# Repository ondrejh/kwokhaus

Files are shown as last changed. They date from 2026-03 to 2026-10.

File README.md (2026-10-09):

# Kwokhaus

Attempt on some eggish automation.

# ToDo

- [ ] remote setting
- [ ] non volatile config (not hard coded)

---

## Kwokhaus

- door motor controll
- remote connection with Meshtastic (encrypted LoRa)
- Home Assistant integration

## Kwakhaus

### Lock

Simple lock controll with serial connection to Meshtastic.

Source directory fw/src_lock

- [x] clear project (remove display and rtc)
- [x] check lock / unlock response
- [x] create unlock trigger (remote only)
- [x] repeat status message every half an hour

- [x] connect meshtastic message to home assistant
- [x] find out how to send messages from home assistant

- [ ] light with dimmer
- [ ] return more info on status (voltage, temperature, ect.)

#### Communication protocol

function | command | answer | example
--- | --- | --- | ---
get status | NAME ? | NAME: LODKED/UNLOCKED | RX: ``KWAK ?```
| | | | TX: ```KWAK: LOCKED/UNLOCKED```
unlock | NAME UNLOCK | | RX: ```KWAK UNLOCK```
| | | |
status change | | NAME LOCKED/UNLOCKED | TX: ```KWAK: LOCKED/UNLOCKED```

#### Building, flashing

From source directory ```fw``` run ```./rebuild_lock.sh```. Reset the board to bootloader by ```./utils/reset.sh```, flash it by ```./utils/flash.sh```.

#### Connecting MQTT to HA

Let there be ```mqtt.yaml``` file in your config. And let there be in you ```configuration.yaml``` file line ```mqtt: !include mqtt.yaml```. Than, somewhere it the file there shoul be:

```
  - name: "MediumFast Last Message"
    unique_id: "mediumfast_last_message"
    state_topic: !secret meshtastic_mediumfast_topic
    value_template: >-
      {% if value_json.payload.text is defined %}
        {{ (value_json.payload.text) }}
      {% else %}
        {{ this.state }}
      {% endif %}
```

Note that, you also need to have secret definition in your secret.yaml file. This is how HA works. Love it or hate it.

From now on, youre having last MediumFast message in sensor.medium_fast_message entity. One can probably imagine how to change this for his own secret channel. Cause the otherone can probably imagine, its not a good idea to have LOCK driver connected to the public channel.

### Key

Dedicated Meshtastic connected device, monitoring Lock status. It has an RGB led to indicate whether lock is locked or unlocked. It also has the button to unlock it remotelly.

#### ToDo

- [x] chatch lock unlock messages, display
- [x] detect button press, send unlock message
- [x] send status request when no status update

##### Technical

- [ ] wifi, mqtt reconnecting
- [ ] mqtt dedicated files (not to plague main)

#### Features

- button
  - to unlock remote lock
- rgb led
  - to indicate remote lock status
- mqtt connection
  - bridge between secret Meshtastic channel and MQTT
  - backup channel for HA, in case main transceiver doesn't work

#### Prototype

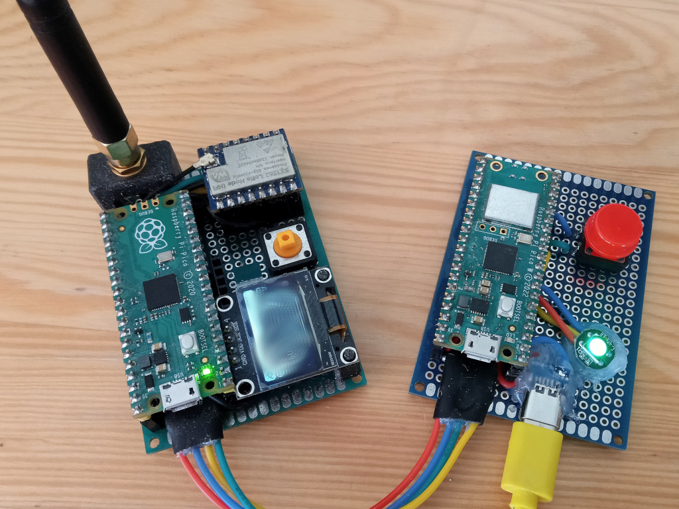
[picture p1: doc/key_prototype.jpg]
KwakKey prototype with ohM3 meshtastic modem


---

Obsolette

### Idea (not to forget)

- rubber duck splash screen

### Siple tasks

- [x] trigger by pushbutton (test)
- [ ] trigger on time
- [ ] send status on idle (every 15 minutes)
- [ ] send status on event
- [ ] draw display function chart
- [x] create and test function to store data in flash (or find lib)
  - improve nvdata.c/h
- [x] parse incoming messages
  - [x] reply on ?
  - [x] T to set time
  - [x] Z to set zone
  - [x] U to set unlock time
- [x] simple pushbutton (any bool input) filtering
- [ ] measure trigger charge voltage

### Hardware needed

- [x] rtc module
- [x] display
- [x] communication port (uart)
- [ ] charge pump
  - to charge trigger from lower voltage (single lipo)

### Functionality and features

- [x] filter incoming messages
- [x] show time
- [x] set time
- [x] set trigger time
- [ ] set time, trigger and zone localy (button, display)
- [ ] trigger on time
- [ ] showing status on display (unlocked, locked, next unlock in ..)
- [x] remote addministration by com. port

### Communication protocol (so far)

function | command | answer | example
--- | --- | --- | ---
get status | NAME ? | NAME LODKED/UNLOCKED Uhh:mm Thh:mm(z) | RX: ```KWAK ?```
| | | | TX: ```KWAK: LOCKED U11:03 T10:08(+2)```
set local time | NAME Thh:mm | NAME: Thh:mm | RX: ```KWAK T12:00```
| | | | TX: ```KWAK: T12:00```
set unlock time (local) | NAME Uhh:mm | NAME: Uhh:mm | RX: ```KWAK U12:01```
| | | | TX: ```KWAK: U12:01```
set zone | NAME Z+/-z | NAME: Z+/-z | RX: ```KWAK Z+1```
| | | | TX: ```KWAK: Z+1```

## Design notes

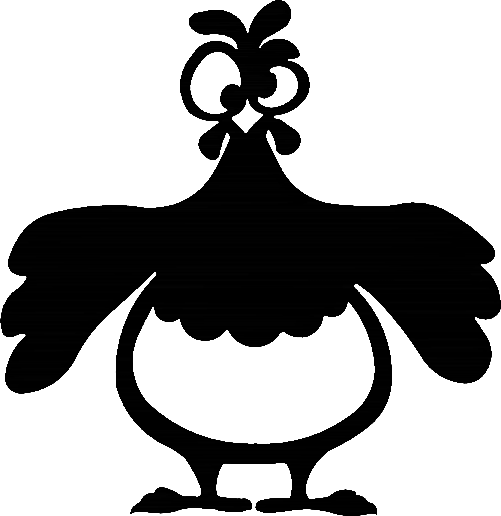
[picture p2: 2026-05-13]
jine/slepice.png

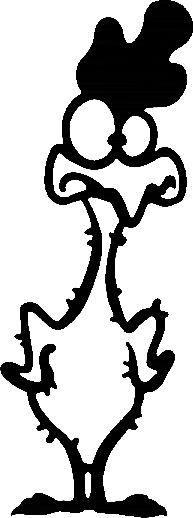
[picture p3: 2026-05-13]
jine/kohout.png

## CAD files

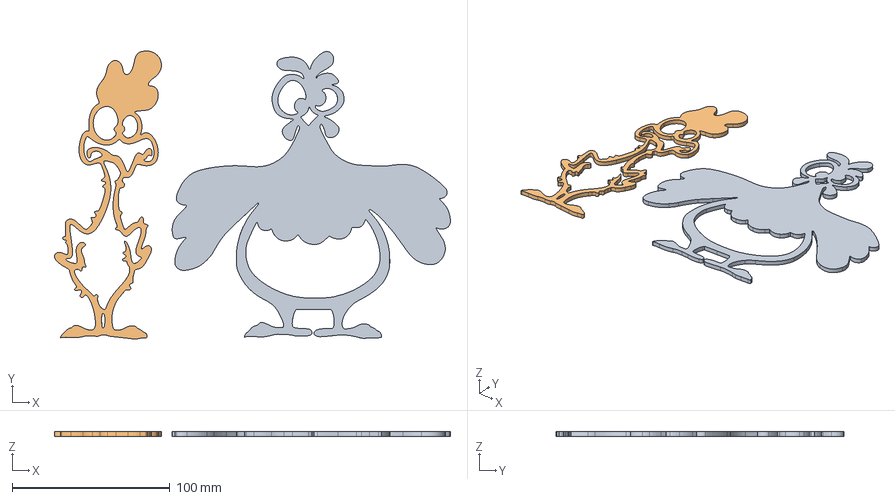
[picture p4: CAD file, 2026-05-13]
jine/obraz.FCStd
251.1 x 182.7 x 3.00 mm
slepice
kohout

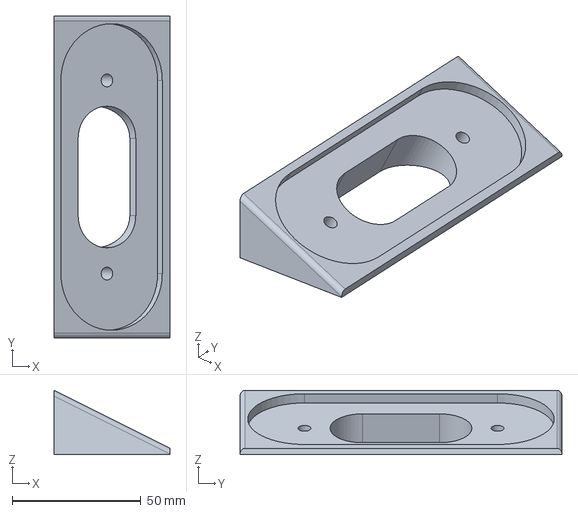
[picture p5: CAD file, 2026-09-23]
model/svetlo.FCStd
45.0 x 125.0 x 25.0 mm

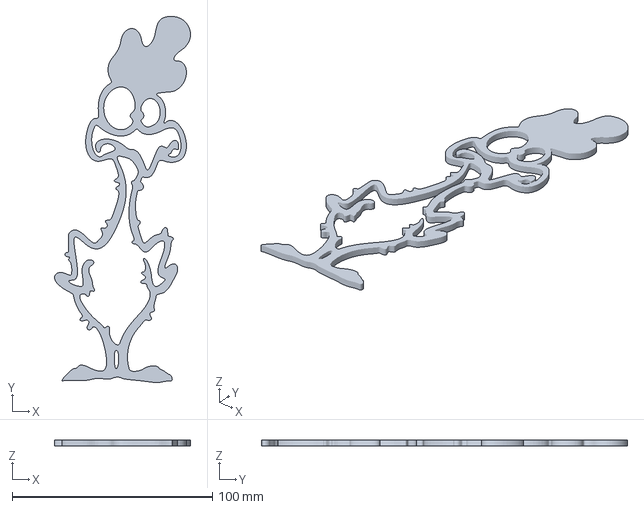
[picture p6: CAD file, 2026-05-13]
jine/kohout.3mf
67.8 x 182.7 x 3.00 mm

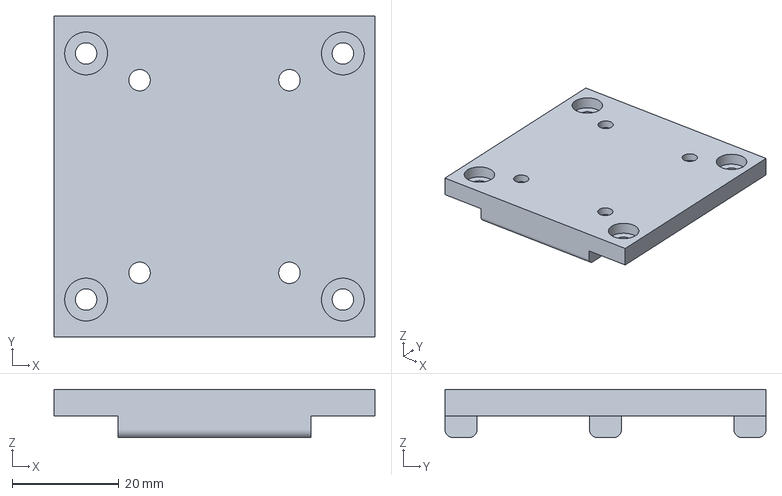
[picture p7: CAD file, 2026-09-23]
model/zdroj-plate.3mf
60.0 x 60.0 x 9.00 mm

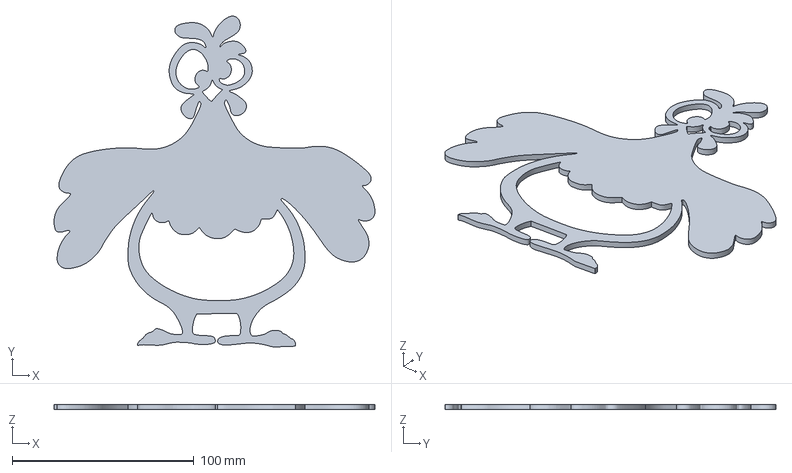
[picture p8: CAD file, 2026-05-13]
jine/slepice.3mf
176.5 x 181.9 x 3.00 mm

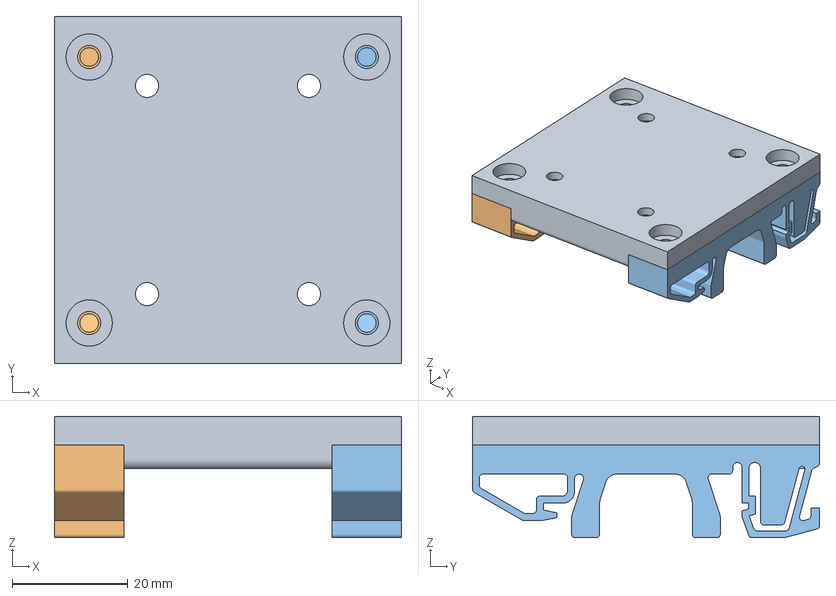
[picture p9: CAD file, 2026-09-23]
model/zdroj.FCStd
60.0 x 60.0 x 21.0 mm
plate
dins_clip1
dins_clip2

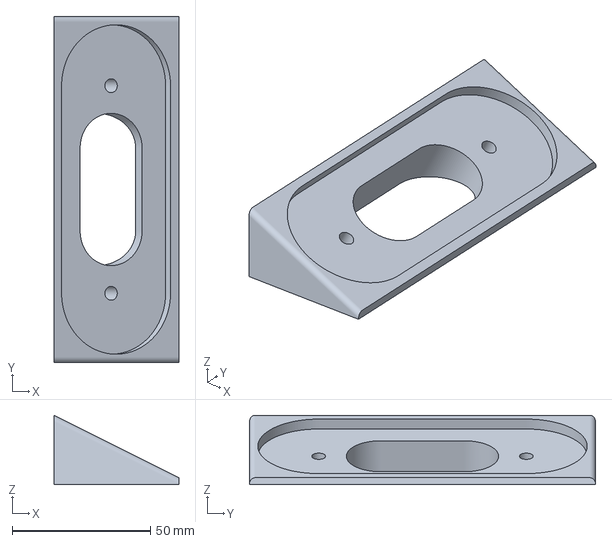
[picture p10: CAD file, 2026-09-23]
model/svetlo-holder.3mf
45.0 x 125.0 x 25.0 mm

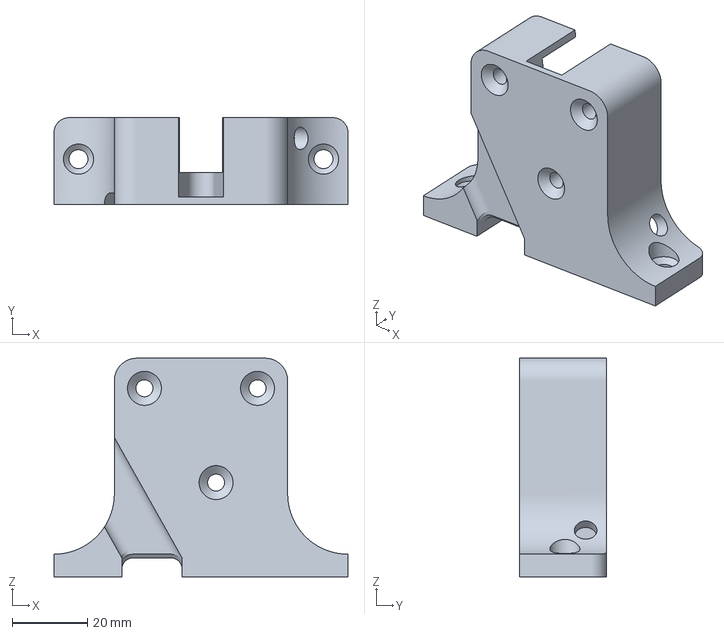
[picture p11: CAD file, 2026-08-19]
model/zamek_kachnik_vetsi-drzak_zamku.3mf
78.0 x 23.0 x 58.0 mm

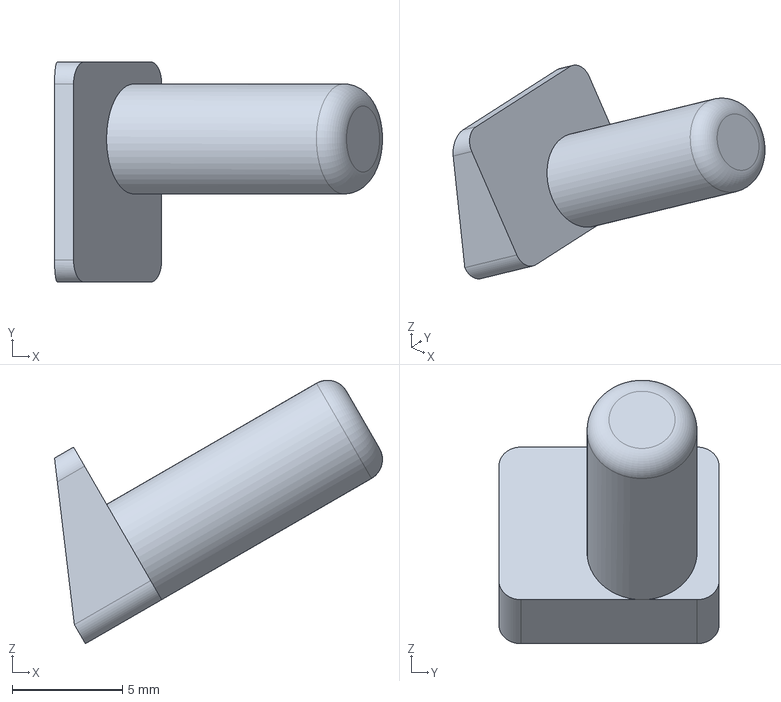
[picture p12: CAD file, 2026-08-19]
model/zamek_kachnik_vetsi.FCStd
14.9 x 10.0 x 12.0 mm

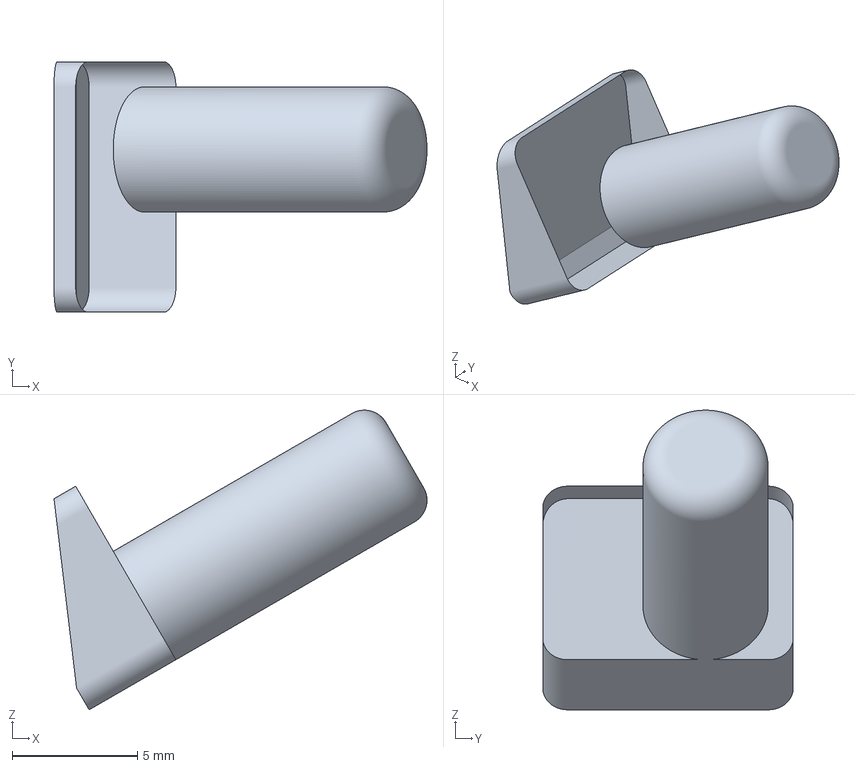
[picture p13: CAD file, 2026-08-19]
model/zamek_kachnik_vetsi-cudlik.3mf
14.9 x 10.0 x 12.0 mm

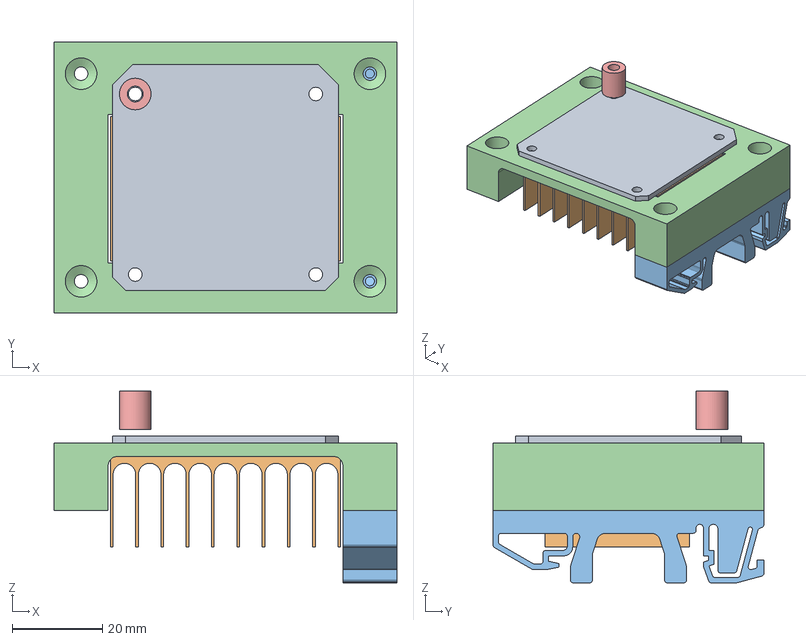
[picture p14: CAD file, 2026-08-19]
model/driver_holder.FCStd
76.0 x 60.0 x 42.5 mm
PCB
Heatsink
din_clip2
thebody
distance

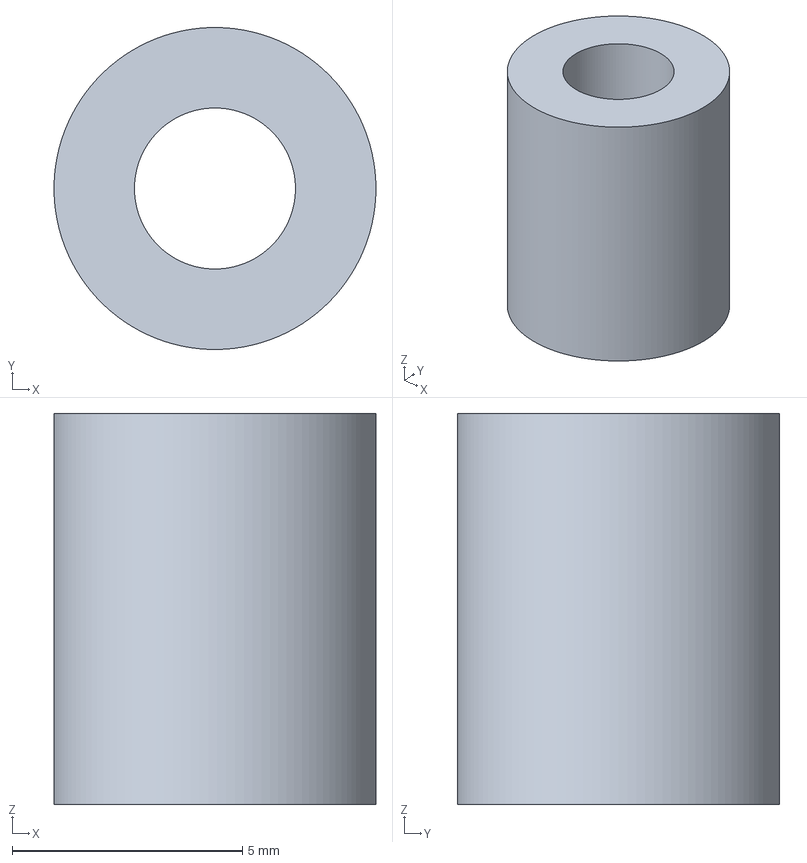
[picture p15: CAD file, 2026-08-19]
model/driver_holder-distance.3mf
7.00 x 7.00 x 8.50 mm

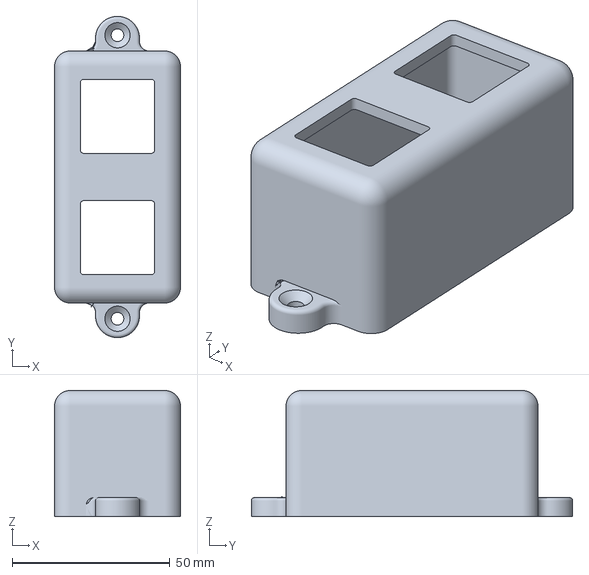
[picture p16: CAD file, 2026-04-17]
model/tlacitka-krabicka.3mf
40.0 x 102.0 x 40.0 mm

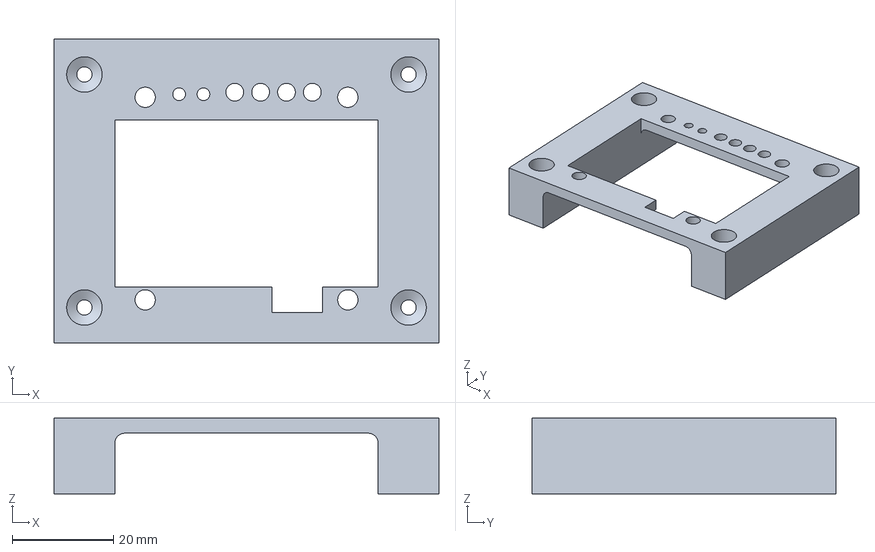
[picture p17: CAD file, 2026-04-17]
model/driver_holder-thebody.3mf
76.0 x 60.0 x 15.0 mm

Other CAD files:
model/tlacitka.FCStd
model/dins_clip.STL
model/driver_holder-din_clip2.3mf
model/zamek_kachnik_krytka_konektoru.FCStd
model/podlozka.FCStd
model/pruzina_kachnik-drzak_pruziny.3mf
model/pruzina_kachnik-prichytka.3mf
model/pruzina_kachnik.FCStd
model/zamek_kachnik-drzak_zamku.3mf
model/zamek_kachnik-drzak_zapadky.3mf
model/zamek_kachnik-krytka.3mf
model/zamek_kachnik-podlozka.3mf
model/zamek_kachnik.FCStd
model/zamek_kachnik_krytka_konektoru.3mf
model/zamek_kachnik_vetsi-cudlik.stl

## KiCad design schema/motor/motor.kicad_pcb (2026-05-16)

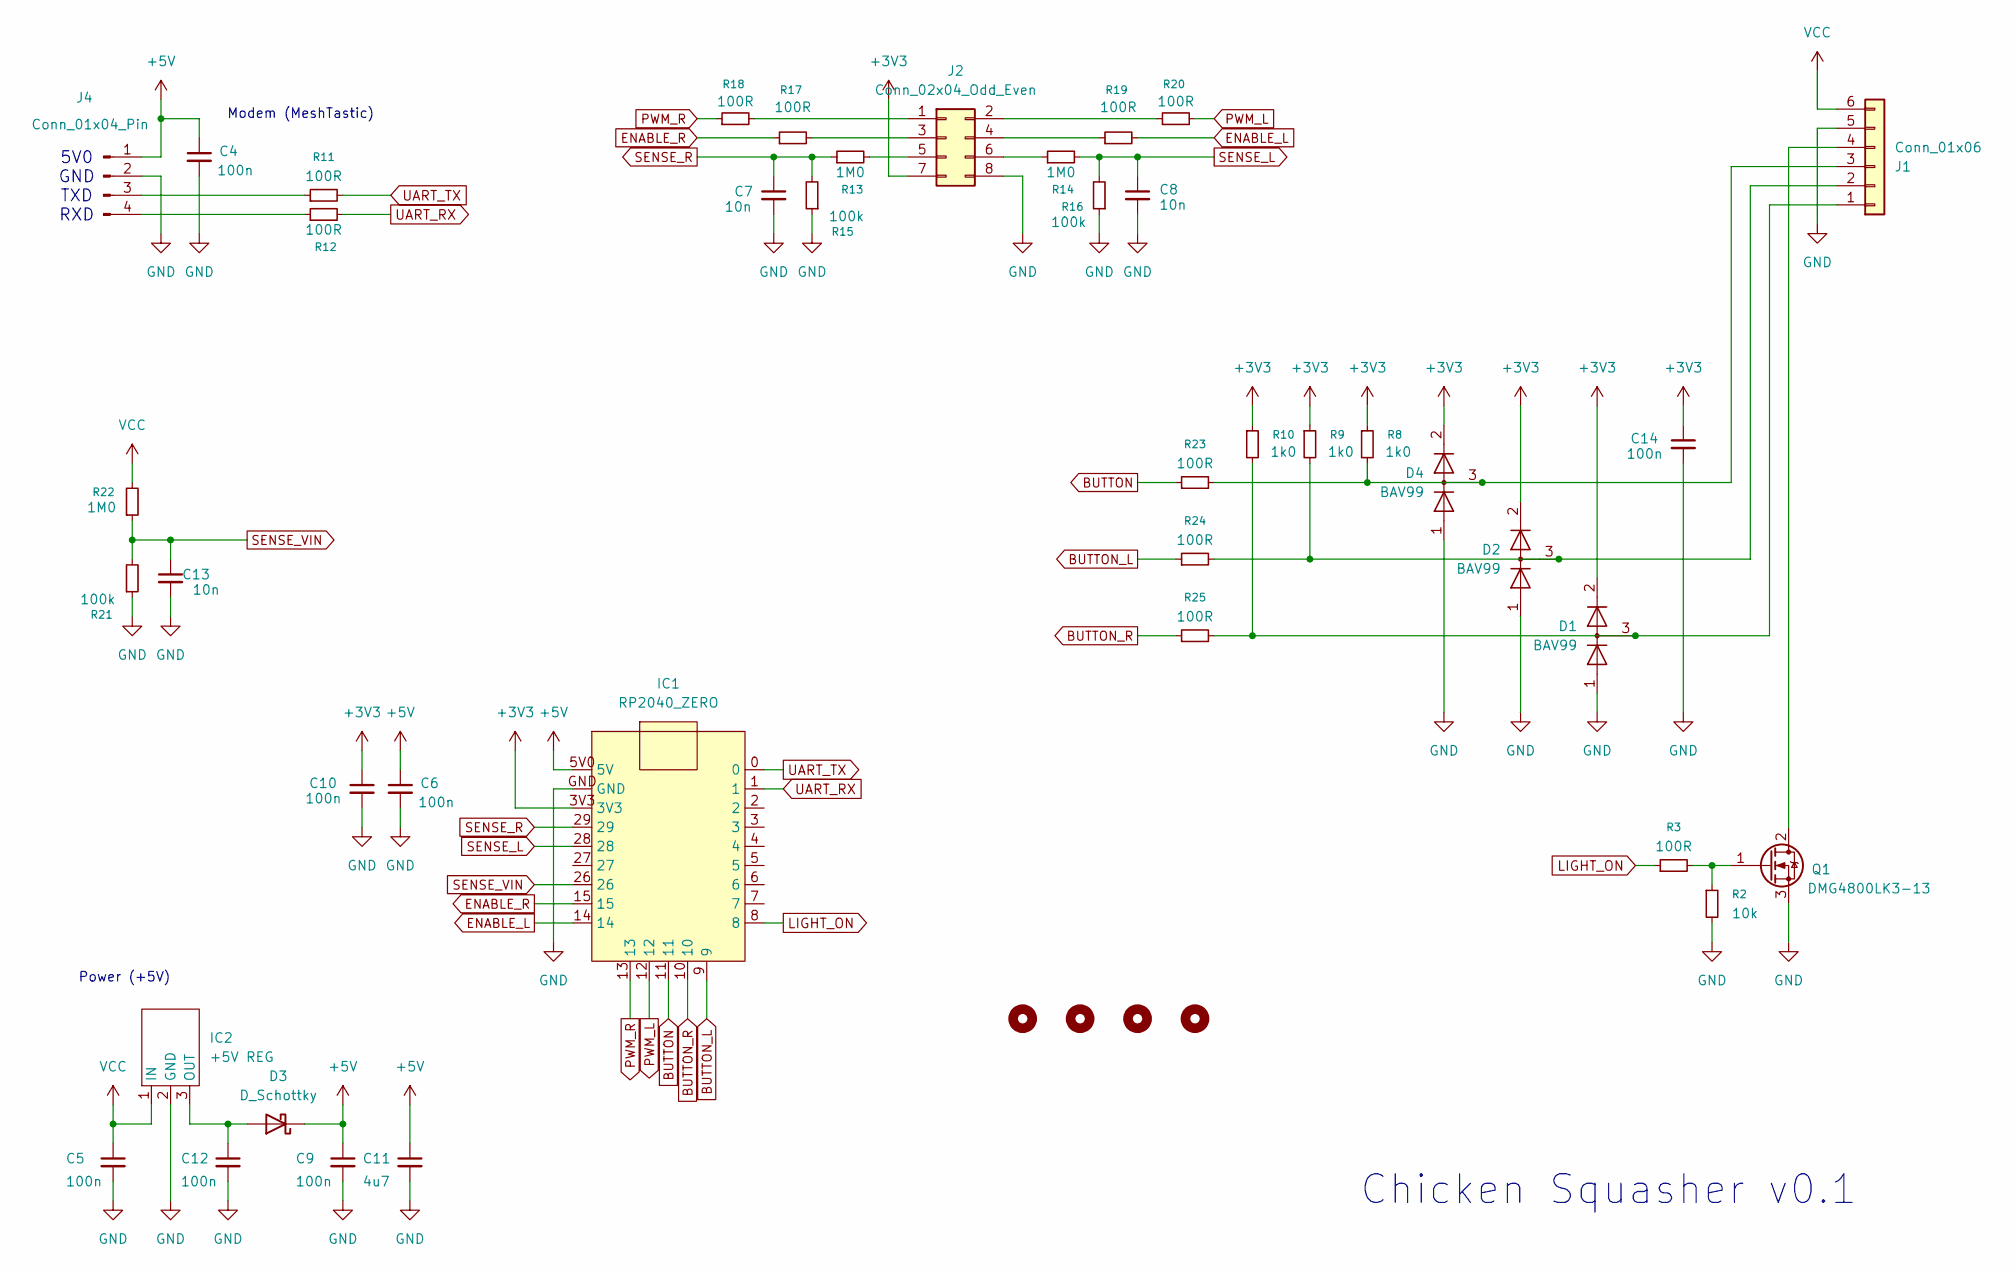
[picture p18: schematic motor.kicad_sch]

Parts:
C4, C5, C6, C9, C10, C12, C14: 100n; C_0603_1608Metric
C7, C8, C13: 10n; C_0603_1608Metric
C11: 4u7; C_1206_3216Metric
D1, D2, D4: BAV99; SOT-23
D3: D_Schottky; D_SOD-123F
H1, H2, H3, H4: MountingHole; MountingHole_3.2mm_M3
IC1: RP2040_ZERO
IC2: +5V REG; Untitled_3
J1: Conn_01x06; TerminalBlock_Phoenix_MKDS-1,5-6-5.08_1x06_P5.08mm_Horizont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
J2: Conn_02x04_Odd_Even; PinSocket_2x04_P2.54mm_Vertical
J4: Conn_01x04_Pin; Solder_Terminal_4p
Q1: DMG4800LK3-13; TO-252-3_TabPin2
R2: 10k; R_0603_1608Metric
R3, R11, R12, R17, R18, R19, R20, R23, R24, R25: 100R; R_0603_1608Metric
R8, R9, R10: 1k0; R_0603_1608Metric
R13, R14, R22: 1M0; R_0603_1608Metric
R15, R16, R21: 100k; R_0603_1608Metric

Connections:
+3V3: C10.1, C14.1, D1.2 (A), D2.2 (A), D4.2 (A), IC1.3V3, J2.7, R8.1, R9.1, R10.1
+5V: C4.1, C6.1, C9.1, C11.1, D3.1 (K), IC1.5V0 (5V), J4.1
BUTTON: IC1.11, R23.1
BUTTON_L: IC1.9, R24.1
BUTTON_R: IC1.10, R25.1
ENABLE_L: IC1.14, R19.2
ENABLE_R: IC1.15, R17.1
GND: C4.2, C5.2, C6.2, C7.2, C8.2, C9.2, C10.2, C11.2, C12.2, C13.2, C14.2, D1.1 (K), D2.1 (K), D4.1 (K), IC1.GND, IC2.2 (GND), J1.5, J2.8, J4.2, Q1.3 (S), R2.2, R15.1, R16.1, R21.1
LIGHT_ON: IC1.8, R3.1
unnamed: C12.1, D3.2 (A), IC2.3 (OUT)
unnamed: D1.3 (K), J1.1, R10.2, R25.2
unnamed: D2.3 (K), J1.2, R9.2, R24.2
unnamed: D4.3 (K), J1.3, R8.2, R23.2
unnamed: J1.4, Q1.2 (D)
unnamed: J2.1, R18.2
unnamed: J2.2, R20.1
unnamed: J2.3, R17.2
unnamed: J2.4, R19.1
unnamed: J2.5, R13.2
unnamed: J2.6, R14.1
unnamed: J4.3, R11.1
unnamed: J4.4, R12.1
unnamed: Q1.1 (G), R2.1, R3.2
PWM_L: IC1.12, R20.2
PWM_R: IC1.13, R18.1
SENSE_L: C8.1, IC1.28, R14.2, R16.2
SENSE_R: C7.1, IC1.29, R13.1, R15.2
SENSE_VIN: C13.1, IC1.26, R21.2, R22.1
UART_RX: IC1.1, R12.2
UART_TX: IC1.0, R11.2
VCC: C5.1, IC2.1 (IN), J1.6, R22.2

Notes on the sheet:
Power (+5V)
Chicken Squasher v0.1
Modem (MeshTastic)
5V0 GND TXD RXD

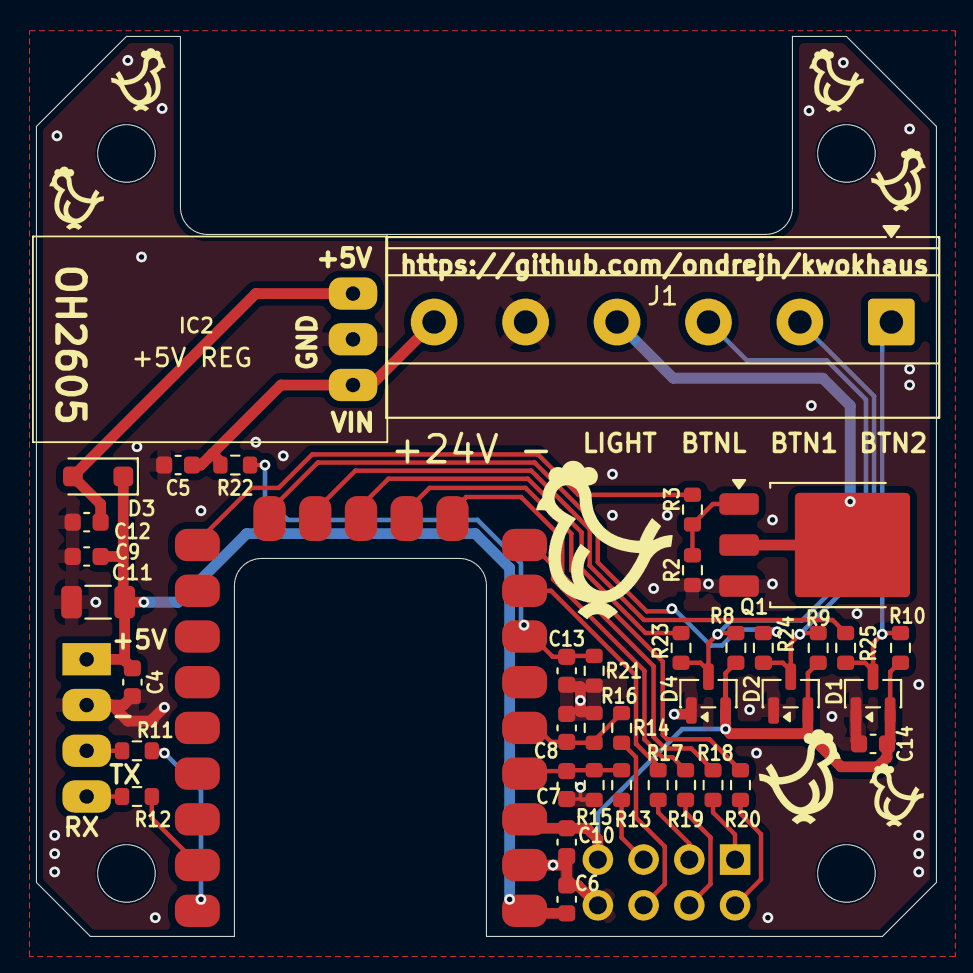
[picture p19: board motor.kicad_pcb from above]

Board: 2 copper layers, 50.0 x 50.0 mm, 45 parts (1 on the bottom side), 31 nets.

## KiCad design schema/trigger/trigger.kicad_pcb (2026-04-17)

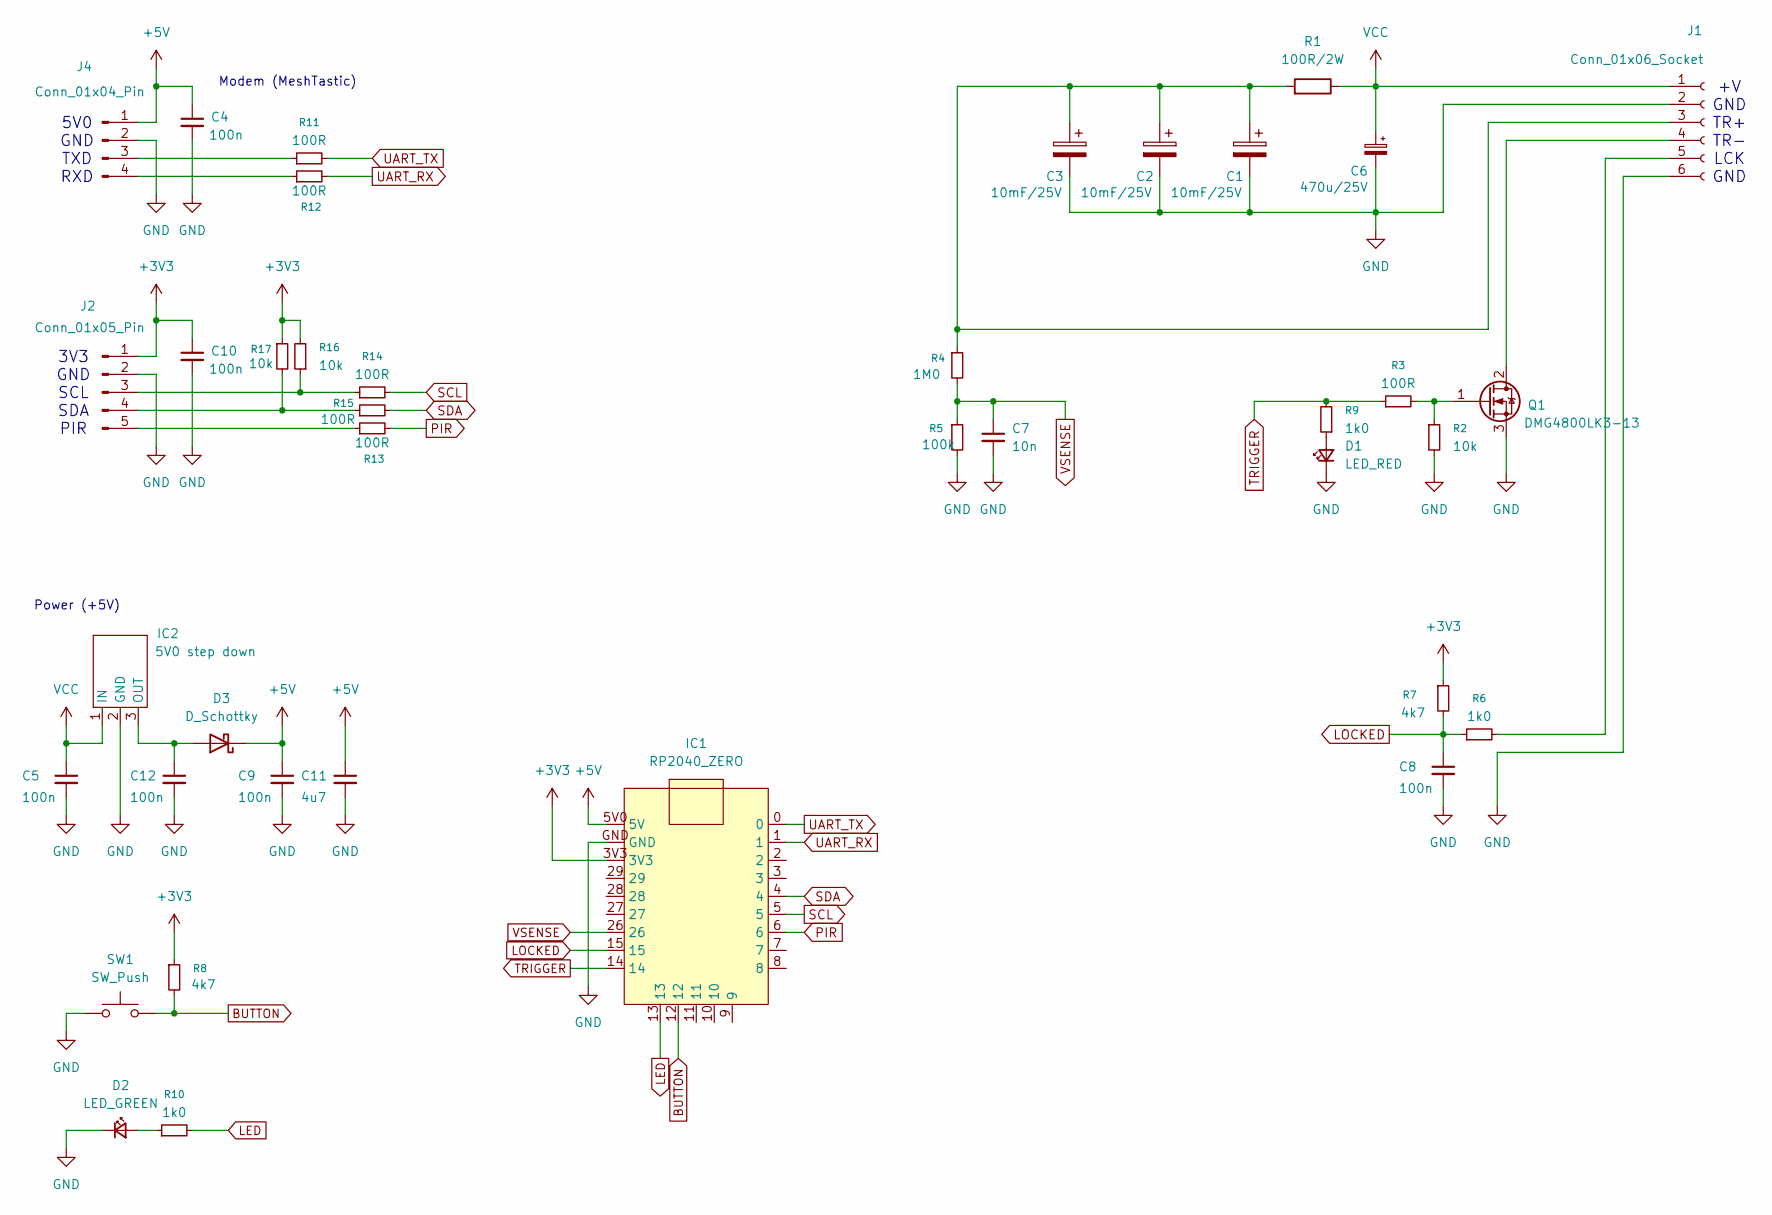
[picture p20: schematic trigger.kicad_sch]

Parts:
C1, C2, C3: 10mF/25V; C_36x18
C4, C5, C8, C9, C10, C12: 100n; C_0603_1608Metric
C6: 470u/25V; CP_Radial_D8.0mm_P3.50mm
C7: 10n; C_0603_1608Metric
C11: 4u7; C_1206_3216Metric
D1: LED_RED; LED_0805_2012Metric
D2: LED_GREEN; LED_0805_2012Metric
D3: D_Schottky; D_SOD-123F
IC1: RP2040_ZERO
IC2: 5V0 step down; Untitled_3
J1: Conn_01x06_Socket; Solder_Terminal_6p
J2: Conn_01x05_Pin; Solder_Terminal_5p
J4: Conn_01x04_Pin; Solder_Terminal_4p
Q1: DMG4800LK3-13; TO-252-3_TabPin2
R1: 100R/2W; R_Axial_DIN0414_L11.9mm_D4.5mm_P15.24mm_Horizontal
R2, R16, R17: 10k; R_0603_1608Metric
R3, R11, R12, R13, R14, R15: 100R; R_0603_1608Metric
R4: 1M0; R_0603_1608Metric
R5: 100k; R_0603_1608Metric
R6, R9, R10: 1k0; R_0603_1608Metric
R7, R8: 4k7; R_0603_1608Metric
SW1: SW_Push; SW_SPST_SKQG_WithStem

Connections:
+3V3: C10.1, IC1.3V3, J2.1, R7.1, R8.1, R16.2, R17.1
+5V: C4.1, C9.1, C11.1, D3.1 (K), IC1.5V0 (5V), J4.1
BUTTON: IC1.12, R8.2, SW1.2
GND: C1.2, C2.2, C3.2, C4.2, C5.2, C6.2, C7.2, C8.2, C9.2, C10.2, C11.2, C12.2, D1.1 (K), D2.1 (K), IC1.GND, IC2.2 (GND), J1.2, J1.6, J2.2, J4.2, Q1.3 (S), R2.2, R5.2, SW1.1
LED: IC1.13, R10.2
LOCKED: C8.1, IC1.15, R6.1, R7.2
unnamed: D1.2 (A), R9.1
unnamed: D2.2 (A), R10.1
unnamed: C12.1, D3.2 (A), IC2.3 (OUT)
unnamed: C1.1, C2.1, C3.1, J1.3, R1.2, R4.1
unnamed: J1.4, Q1.2 (D)
unnamed: J1.5, R6.2
unnamed: J2.3, R14.1, R16.1
unnamed: J2.4, R15.1, R17.2
unnamed: J2.5, R13.1
unnamed: J4.3, R11.1
unnamed: J4.4, R12.1
unnamed: Q1.1 (G), R2.1, R3.2
PIR: IC1.6, R13.2
SCL: IC1.5, R14.2
SDA: IC1.4, R15.2
TRIGGER: IC1.14, R3.1, R9.2
UART_RX: IC1.1, R12.2
UART_TX: IC1.0, R11.2
VCC: C5.1, C6.1, IC2.1 (IN), J1.1, R1.1
VSENSE: C7.1, IC1.26, R4.2, R5.1

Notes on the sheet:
+V GND TR+ TR- LCK GND
3V3 GND SCL SDA PIR
Power (+5V)
Modem (MeshTastic)
5V0 GND TXD RXD

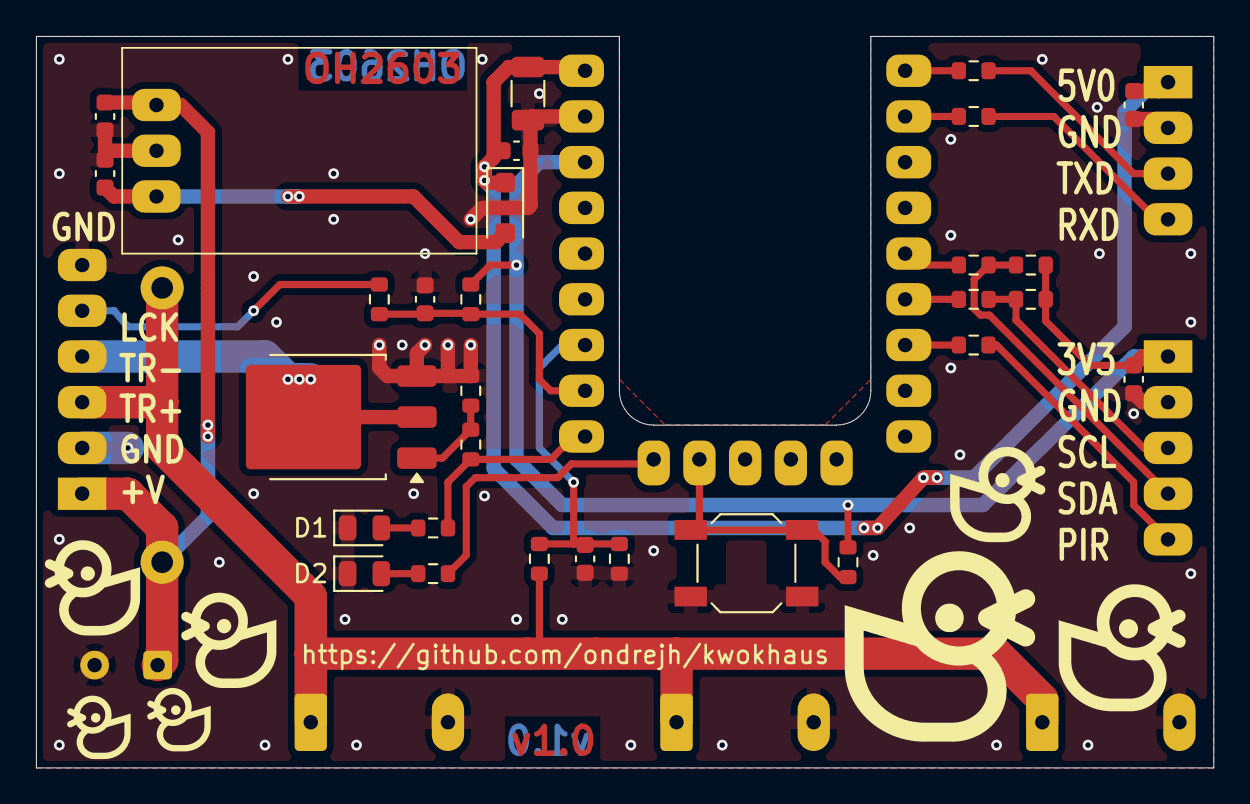
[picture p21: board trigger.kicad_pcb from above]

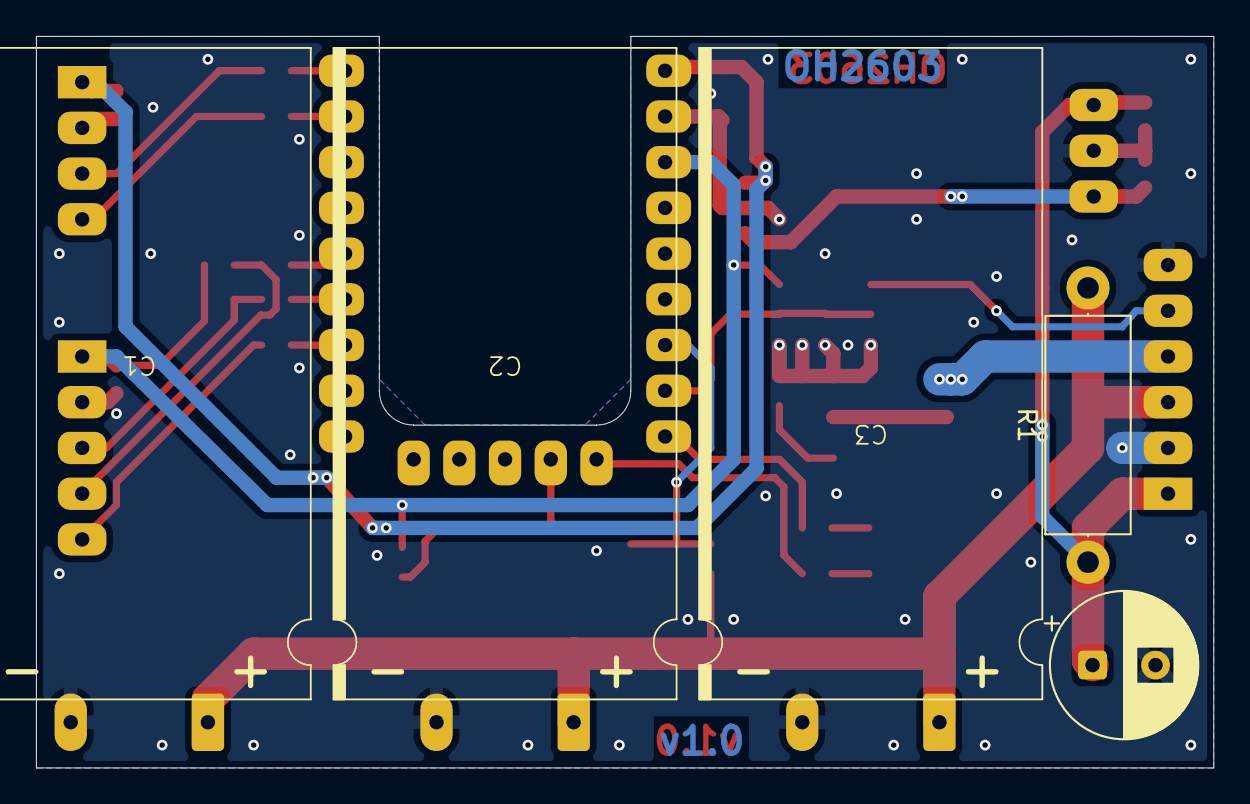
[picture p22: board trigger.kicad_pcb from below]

Board: 2 copper layers, 65.4 x 40.6 mm, 39 parts (5 on the bottom side), 26 nets.

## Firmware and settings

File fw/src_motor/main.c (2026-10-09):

#include "includes.h"

void init(void) {
  // Initialize outputs
  gpio_init(ENABLE_R_PIN);
  gpio_set_dir(ENABLE_R_PIN, GPIO_OUT);
  gpio_init(ENABLE_L_PIN);
  gpio_set_dir(ENABLE_L_PIN, GPIO_OUT);

  gpio_init(PWM_R_PIN);
  gpio_set_dir(PWM_R_PIN, GPIO_OUT);
  gpio_init(PWM_L_PIN);
  gpio_set_dir(PWM_L_PIN, GPIO_OUT);

  gpio_init(LIGHT_PIN);
  gpio_set_dir(LIGHT_PIN, GPIO_OUT);

  // Initialize nvdata (load configuration)
  load_config(&config);

  // Initialize communication
  comm_init();

  // initialize PWM
  // 1. nastaveni pwm pinu
  gpio_set_function(PWM_L_PIN, GPIO_FUNC_PWM);
  gpio_set_function(PWM_R_PIN, GPIO_FUNC_PWM);
  gpio_set_function(LIGHT_PIN, GPIO_FUNC_PWM);

  // 2. zjisti bloky (slices) pwm
  uint sliceL = pwm_gpio_to_slice_num(PWM_L_PIN);
  uint sliceR = pwm_gpio_to_slice_num(PWM_R_PIN);
  uint sliceLight = pwm_gpio_to_slice_num(LIGHT_PIN);

  // 3. nastaveni periody
  pwm_set_wrap(sliceL, PWM_PERIOD);
  pwm_set_wrap(sliceR, PWM_PERIOD);
  pwm_set_wrap(sliceLight, PWM_PERIOD);

  // 4. nastaveni stridy (Duty Cycle) ~ 0
  pwm_set_gpio_level(PWM_L_PIN, 0);
  pwm_set_gpio_level(PWM_R_PIN, 0);
  pwm_set_gpio_level(LIGHT_PIN, 0);

  // 5. spusteni PWM bloku
  pwm_set_enabled(sliceL, true);
  pwm_set_enabled(sliceR, true);
  pwm_set_enabled(sliceLight, true);

  // initialize ADC
  adc_module_init();

  // Initialize onboard NeoPixel
  ws2812_init(RGB_LED_PIN);
}

#define COMM_BUFLEN 128
uint8_t comm_buff[COMM_BUFLEN];
uint8_t usb_comm_buff[COMM_BUFLEN];

GateState gate = GATE_UNKNOWN;
bool light = false;

int main() {
  stdio_init_all();         // Inicializace USB CDC

  init();

  bool led = false;//, trig = false;
  int32_t tLed = 0, tDisp = 0, tTrig = 0, tTim = 0, tAdc = 0;
  uint8_t r = 0x00, g = 0x00, b = 0x00;

  btn_ctx_t btnL, btnR, btnLight;
  button_init(&btnL, BUTTON_L_PIN);
  button_init(&btnR, BUTTON_R_PIN);
  button_init(&btnLight, BUTTON_LIGHT_PIN);

  //comm_init();

  tDisp = millis();

  uint32_t cnt = 0;
  int32_t adc[3];

  uint32_t pwm = 0;
  uint16_t voltage = 0;

  uint8_t motor_status = 0;
  uint8_t motor_status_last = 0;
  uint32_t motor_running_t = 0;
  uint32_t motor_current_t = 0;
  int32_t motor_current_offset[2] = {0, 0};
  uint32_t motor_current_offset_t = 0;
  bool motor_current_offset_calibrated = false;
  bool motor_current_measured = false;

  uint32_t tLastTx = 0;
  bool status_sent = false;
  bool light_last = false;
  uint32_t status_change_t = millis();
  bool status_change_pending = true;
  uint32_t status_change_timeout = 1000 + (get_rand_32() % STATUS_CHANGE_TIMEOUT);

  uint32_t tLight = 0;
  uint32_t lightPwm = 0;
  uint32_t lightDime = LIGHT_DIMMING;
  uint32_t tLightOff = 0;
  uint32_t tLightOn = 0;

  while (true) {
    int32_t now = millis();
    event_t event = EVENT_NONE;

    // receive commands from UART
    int comrx = comm_poll(now, 100, comm_buff, COMM_BUFLEN);
    if (comrx) {
      comm_buff[comrx] = '\0';
      printf("Rx: %.*s\n", COMM_BUFLEN, comm_buff);
      comm_parse(comm_buff, comrx, COMM_BUFLEN);
    }

    // receive commands from USB
    int usb_comrx = usb_comm_poll(now, 100, usb_comm_buff, COMM_BUFLEN);
    if (usb_comrx) {
      usb_comm_buff[usb_comrx] = '\0';
      printf("USB Rx: %.*s\n", COMM_BUFLEN, usb_comm_buff);
      comm_parse(usb_comm_buff, usb_comrx, COMM_BUFLEN);
    }

    // detect status change and send status event if needed
    if ((motor_status != motor_status_last) ||
        (light != light_last)) {
      motor_status_last = motor_status;
      light_last = light;
      status_change_t = now;
      status_change_pending = true;
      status_change_timeout = STATUS_CHANGE_TIMEOUT;
    }
    else if (status_change_pending &&
             ((now - status_change_t) >= status_change_timeout)) {
      if (event_queue_push(EVENT_STATUS) || event_queue_contains(EVENT_STATUS))
        status_change_pending = false;
    }

    // button polling and event generation
    button_poll(&btnL, now);
    button_poll(&btnR, now);
    button_poll(&btnLight, now);
    queue_button_events(btnL.st, btnR.st, btnLight.st);

    // event processing
    event = event_queue_peek();
    event_result_t event_result = EVENT_HANDLED;

    if ((now - tLastTx) > STATUS_REPEAT_PERIOD)
      event_queue_push(EVENT_STATUS);

    if (event == EVENT_STATUS) {
      if (comm_tx_busy() ||
          (status_sent && ((now - tLastTx) < STATUS_REPEAT_PERIOD_MIN))) {
        event_result = EVENT_RETRY;
      }
      else {
        tLastTx = now;
        status_sent = true;
        status_change_timeout = STATUS_CHANGE_TIMEOUT;
        comrx = sprint_status(comm_buff, COMM_BUFLEN);
        comm_write(comm_buff, comrx);
        printf("TX: %s\n", comm_buff);
      }
    }

    if (event == EVENT_CMD_LIGHT_ON) {
      light = true;
      lightDime = LIGHT_DIMMING;
      tLightOff = 0; // switch off automatic switching off, clear?
    }
    if (event == EVENT_CMD_LIGHT_OFF) {
      light = false;
      lightDime = LIGHT_DIMMING;
    }
    if (event == EVENT_BTN_LIGHT) {
      light = !light;
      lightDime = LIGHT_DIMMING_BTN;
      if (light) {
        tLightOn = now;
        tLightOff = LIGHT_AUTO_OFF;
      }
    }

    if ((event == EVENT_BTN_OPEN) || (event == EVENT_BTN_CLOSE)) {
      if (motor_status & MOTOR_RUNNING) {
        printf("MOTOR STOP\n");
        motor_status &= ~MOTOR_RUNNING;
      }
      else if (event == EVENT_BTN_OPEN) {
        motor_status |= MOTOR_GO_UP;
        motor_running_t = now;
      }
      else {
        motor_status |= MOTOR_GO_DOWN;
        motor_running_t = now;
      }
    }
    else if ((motor_status & MOTOR_RUNNING) == 0) {
      if (event == EVENT_CMD_OPEN) {
        motor_status |= MOTOR_GO_UP;
        motor_running_t = now;
      }
      else if (event == EVENT_CMD_CLOSE) {
        motor_status |= MOTOR_GO_DOWN;
        motor_running_t = now;
      }
    }

    if (motor_status & MOTOR_RUNNING) {
      if ((now - motor_running_t) > MOTOR_SAFETY_TIMEOUT) { // safety timeout
        printf("MOTOR TIMEOUT\n");
        motor_status &= ~MOTOR_RUNNING;
      }
    }

    // force motor up/down
    if (btnL.st == BTNST_HOLD) {
      motor_status |= MOTOR_FORCE_UP;
      motor_status &= ~(MOTOR_GO_DOWN | MOTOR_FORCE_DOWN | MOTOR_GO_UP);
    }
    else if (btnR.st == BTNST_HOLD) {
      motor_status |= MOTOR_FORCE_DOWN;
      motor_status &= ~(MOTOR_GO_UP | MOTOR_FORCE_UP | MOTOR_GO_DOWN);
    }
    else {
      motor_status &= ~(MOTOR_FORCE_UP | MOTOR_FORCE_DOWN);
    }

    if (motor_status & (MOTOR_GO_UP | MOTOR_FORCE_UP)) {
      gpio_put(ENABLE_L_PIN, true);
      gpio_put(ENABLE_R_PIN, true);
      pwm_set_gpio_level(PWM_R_PIN, motor_current_offset_calibrated ? pwm : 0);
      pwm_set_gpio_level(PWM_L_PIN, 0);
    }
    else if (motor_status & (MOTOR_GO_DOWN | MOTOR_FORCE_DOWN)) {
      gpio_put(ENABLE_L_PIN, true);
      gpio_put(ENABLE_R_PIN, true);
      pwm_set_gpio_level(PWM_R_PIN, 0);
      pwm_set_gpio_level(PWM_L_PIN, motor_current_offset_calibrated ? pwm : 0);
    }
    else {
      gpio_put(ENABLE_L_PIN, false);
      gpio_put(ENABLE_R_PIN, false);
      pwm_set_gpio_level(PWM_R_PIN, 0);
      pwm_set_gpio_level(PWM_L_PIN, 0);
    }

    // read ADC and calculate voltage and PWM value
    if (adc_poll(now, adc)) {
      voltage = adc2u(adc[0]);
      pwm = v2pwm(voltage);
    }

#ifdef DEBUG
    if ((now - tAdc) > 20) {
      tAdc = now;
      printf("%04X %04X %04X\n", (unsigned int)adc[0], (unsigned int)adc[1], (unsigned int)adc[2]);
      //printf("%0.01fV, %d\n", (float)voltage/1000.0, pwm);
      //printf("Motor status: %x\n", motor_status);
    }
#endif

    // motor current monitoring
    if (motor_status & MOTOR_RUNNING) {
      motor_status &= ~MOTOR_IS_END;
      gate = GATE_UNKNOWN;
      // check if motor current is above threshold, if not, stop motor
      if (!motor_current_offset_calibrated) { // calibrate motor current offset first
        motor_current_t = now;
        if ((now - motor_current_offset_t) > MOTOR_CURRENT_OFFSET_TIMEOUT) {
          motor_current_offset[0] = adc[1];
          motor_current_offset[1] = adc[2];
          motor_current_offset_calibrated = true;
          printf("MOTOR CURRENT OFFSET: %04X %04X\n", (unsigned int)motor_current_offset[0], (unsigned int)motor_current_offset[1]);
          motor_current_offset_t = now;
          motor_current_measured = false;
        }
      }
      else {
        if (!motor_current_measured && ((now - motor_current_offset_t) > MOTOR_CURRENT_OFFSET_TIMEOUT)) {
          int32_t current1 = (int32_t)adc[1] - motor_current_offset[0];
          int32_t current2 = (int32_t)adc[2] - motor_current_offset[1];
          printf("MOTOR CURRENT: %ld %ld\n", (long)current1, (long)current2);
          motor_current_measured = true;
        }
        if ((adc[1] > (motor_current_offset[0] + CURRENT1_MIN)) || (adc[2] > (motor_current_offset[1] + CURRENT2_MIN))) {
          motor_current_t = now;
        }
        else if ((now - motor_current_t) > MOTOR_CURRENT_TIMEOUT) {
          if (motor_status & MOTOR_GO_UP) {
            motor_status |= MOTOR_IS_UP;
            gate = GATE_OPEN;
            event_queue_push(EVENT_MOTOR_IS_UP);
          }
          else if (motor_status & MOTOR_GO_DOWN) {
            motor_status |= MOTOR_IS_DOWN;
            gate = GATE_CLOSED;
            event_queue_push(EVENT_MOTOR_IS_DOWN);
          }
          motor_status &= ~MOTOR_RUNNING;

          // motor stopped - start light timer if light is on
          if (light) {
            tLightOn = now;
            tLightOff = LIGHT_DOOR_AUTO_OFF;
            lightDime = LIGHT_DIMMING; // slow dimming
          }
        }
      }
    } else {
      motor_current_t = now;
      motor_current_offset_t = now;
      motor_current_offset_calibrated = false;
    }

    // automatic light off
    if (light && (tLightOff != 0) && ((now - tLightOn) > tLightOff)) {
      light = false;
    }

    // set light output according to light status
    if ((now - tLight) > 40) {
      tLight = now;
      if (light) {
        if (lightPwm < pwm) {
          lightPwm += lightDime;
          if (lightPwm > pwm)
            lightPwm = pwm;
        }
      }
      else {
        if (lightPwm > 0) {
          if (lightPwm > lightDime) {
            lightPwm -= lightDime;
          }
          else {
            lightPwm = 0;
          }
        }
      }
      pwm_set_gpio_level(LIGHT_PIN, lightPwm);
    }

    // led status
    if ((now - tLed) > 250) {
      tLed = now;
      if (motor_status & (MOTOR_GO_UP | MOTOR_FORCE_UP)) {
        g = (g == 0x10) ? 0 : 0x10;
        r = 0;
      }
      else if (motor_status & (MOTOR_GO_DOWN | MOTOR_FORCE_DOWN)) {
        r = (r == 0x10) ? 0 : 0x10;
        g = 0;
      }
      else if (motor_status & MOTOR_IS_END) {
        g = (motor_status & MOTOR_IS_UP) ? 0x10 : 0;
        r = (motor_status & MOTOR_IS_DOWN) ? 0x10 : 0;
      }
      else {
        r = g = 0;
      }
      b = light?0x08:0;
      put_pixel(urgb_u32(r,g,b));
    }

    if (event_result == EVENT_HANDLED) {
      event_queue_pop();
      event_print(event);
    }

  }
}

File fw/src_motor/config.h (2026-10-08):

#ifndef __CONFIG_H__
#define __CONFIG_H__

// Name will be used as comm identifier
// ToDo: move those into nvram section, create some configuration
// Note: This way I have to build FW for the same HW twice, with
// different comm id. I can imagine config system using USB/UART,
// store data into the section not affected by FW.

#define DEV_NAME "KWOK"
//#define DEV_NAME "KMUT" // second door for (meat) broiler chicken
//#define DEV_NAME "TEST"
//#define DEBUG

// Status timing
#define STATUS_REPEAT_PERIOD (30 * 60 * 1000)
#define STATUS_CHANGE_TIMEOUT (42 * 1000)
#define STATUS_REPEAT_PERIOD_MIN (5 * 1000)

// GPIO
//#define FIRST_PROTOTYPE
#ifdef FIRST_PROTOTYPE

// pin configuration of first prototype
#warning "First prototype pin configuration"

#define BUTTON_LIGHT_PIN 11
#define BUTTON_L_PIN 14
#define BUTTON_R_PIN 15

#define ENABLE_R_PIN 8
#define ENABLE_L_PIN 7
#define PWM_R_PIN 6
#define PWM_L_PIN 5

#define LIGHT_PIN 12

#else // ifdef FIRST_PROTOTYPE

#define BUTTON_L_PIN 9
#define BUTTON_R_PIN 10
#define BUTTON_LIGHT_PIN 11

#define ENABLE_R_PIN 15
#define ENABLE_L_PIN 14
#define PWM_R_PIN 13
#define PWM_L_PIN 12

#define LIGHT_PIN 8

#endif // else FIRST_PROTOTYPE

#define RGB_LED_PIN 16

#define SENSE_R_PIN 29
#define SENSE_R_ADC 3
#define SENSE_L_PIN 28
#define SENSE_L_ADC 2

#define SENSE_VIN_PIN 26
#define SENSE_VIN_ADC 0

#define ADC_POLL_PERIOD 2
#define ADC_OVERSAMPLE 8

#define PWM_PERIOD 62500 // 5kHz
#define VOLT_FULL_PWR 13000 // mV

#define MOTOR_GO_UP (1<<0)
#define MOTOR_GO_DOWN (1<<1)
#define MOTOR_RUNNING (MOTOR_GO_UP | MOTOR_GO_DOWN | MOTOR_FORCE_UP | MOTOR_FORCE_DOWN)
#define MOTOR_IS_UP (1<<2)
#define MOTOR_IS_DOWN (1<<3)
#define MOTOR_IS_END (MOTOR_IS_UP | MOTOR_IS_DOWN)
#define MOTOR_FORCE_UP (1<<4)
#define MOTOR_FORCE_DOWN (1<<5)
#define MOTOR_FORCE (MOTOR_FORCE_UP | MOTOR_FORCE_DOWN)

#define MOTOR_SAFETY_TIMEOUT 30000 // ms (stop motor if it runs for too long without reaching end position)
#define MOTOR_CURRENT_TIMEOUT 400 // ms (stop motor if it runs without current - end switch is reached
#define MOTOR_CURRENT_OFFSET_TIMEOUT 100 // ms (calibrate current offset after motor start)
#define CURRENT1_MIN 0x150 // ADC value (current threshold for motor 1)
#define CURRENT2_MIN 0x040 // ADC value (current threshold for motor 2)

#define LIGHT_DIMMING 10
#define LIGHT_DIMMING_BTN 1000

#define LIGHT_AUTO_OFF 120000 // 2 min
#define LIGHT_DOOR_AUTO_OFF 60 * 5 * 1000 // 5 min

#endif // __CONFIG_H__

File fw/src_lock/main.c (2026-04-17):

#include "includes.h"

#define USE_PWM_OUT

const uint16_t adc_vref = 3300; // 3.3V

uint16_t adc2u(uint16_t adc) {
  uint16_t res = (uint32_t)(((uint32_t)adc * adc_vref * 11) / ((uint32_t)4096 * ADC_OVERSAMPLE));
  return (uint16_t)res;
}

uint32_t v2pwm(uint16_t v) {
  if (v == 0) return 0;
  if (v <= VOLT_FULL_PWR) {
    return (uint32_t)PWM_PERIOD;
  }
  uint64_t calc = (uint64_t)PWM_PERIOD * VOLT_FULL_PWR;
  return (uint32_t)(calc / v);
}

bool adc_poll(uint32_t now, uint16_t *adc) {
  static uint32_t tAdc = 0;
  static int cnt = 0;
  static uint16_t a = 0;
  if ((now - tAdc) >= ADC_POLL_PERIOD) {
    tAdc = now;
    adc_select_input(SENSE_VIN_ADC);
    a += adc_read();
    cnt ++;
    if (cnt >= ADC_OVERSAMPLE) {
      *adc = a;
      a = 0;
      cnt = 0;
      return true;
    }
  }
  return false;
}

void init(void) {
  // Initialize outputs
  gpio_init(LED_GREEN_PIN);
  gpio_set_dir(LED_GREEN_PIN, GPIO_OUT);
  gpio_init(TRIGGER_PIN);
  gpio_set_dir(TRIGGER_PIN, GPIO_OUT);
  gpio_init(BUTTON_PIN);
  gpio_set_dir(BUTTON_PIN, GPIO_IN);
  gpio_set_pulls(BUTTON_PIN, true, false);
  gpio_set_dir(LOCK_PIN, GPIO_IN);
  gpio_set_pulls(LOCK_PIN, true, false);

#ifdef USE_PWM_OUT
  // Initialize PWM
  gpio_set_function(TRIGGER_PIN, GPIO_FUNC_PWM);
  uint slTrig = pwm_gpio_to_slice_num(TRIGGER_PIN);
  pwm_set_wrap(slTrig, PWM_PERIOD);
  pwm_set_gpio_level(TRIGGER_PIN, 0);
  pwm_set_enabled(slTrig, true);
#endif

    // initialize ADC
  adc_init();
  adc_gpio_init(SENSE_VIN_PIN);

  // Initialize communication
  comm_init();

  // Initialize onboard NeoPixel
  ws2812_init(16);
}

#define COMM_BUFLEN 128
uint8_t comm_buff[COMM_BUFLEN];

int main() {
  stdio_init_all();         // Inicializace USB CDC

  init();

  bool led = false;
  int32_t tLed = 0;

  bool trig = false;
  int32_t tTrig = 0, tLastTx = 0;
  uint8_t r = 0x00, g = 0x00, b = 0x00; 

  int16_t adcVin = 0;
  int32_t tAdcNot = 0;

  uint32_t pwm = 0;
  uint16_t voltage = 0;

  while (true) {
    int32_t now = millis();
    bool trig_now = false;

    // grab events
    event_t event = get_input_event(now); // input events

    // receive comm
    int comrx = comm_poll(now, 100, comm_buff, COMM_BUFLEN);
    if (comrx) { // echo test
      comrx = strip(comm_buff, comrx);
      if (comrx) {
        comm_buff[comrx] = '\0';
        printf("RX: %s\n", comm_buff);

        comrx = comm_parse(comm_buff, comrx, COMM_BUFLEN, &event);
        if (comrx) {
          comm_buff[comrx] = '\0';
          if (!comm_tx_busy()) {
            tLastTx = now;
            comm_write(comm_buff, comrx);
            printf("TX: %s\n", comm_buff);
          }
          else
            printf("TX BUSY\n");
        }
      }
    }

    if ((!comm_tx_busy()) && ((now - tLastTx) > STATUS_REPEAT_PERIOD)) {
      tLastTx = now;
      comrx = sprint_status(comm_buff, COMM_BUFLEN);
      comm_write(comm_buff, comrx);
      printf("TX: %s\n", comm_buff);
    }

  #ifdef LIFE_LED
    // live led (green)
    if (led && ((now - tLed) >= 10)) {
      led = false;
      b = 0x00;
      put_pixel(urgb_u32(r,g,b));
    }
    if (!led && ((now - tLed) > 2000)) {
      led = true;
      b = 0x10;
      put_pixel(urgb_u32(r,g,b));
      tLed = now;
    }
  #endif

    // event notification
    switch (event) {
      case EVENT_PRESS:
        printf("Button pressed\n");
        break;
      case EVENT_LONGPRESS:
        printf("Button long pressed\n");
        break;
      case EVENT_LOCK:
      case EVENT_UNLOCK:
        printf("Lock %s\n", (event==EVENT_LOCK)?"locked":"unlocked");
        comrx = sprint_status(comm_buff, COMM_BUFLEN);
        comm_write(comm_buff, comrx);
        tLastTx = now;
        break;
      case EVENT_CMD_UNLOCK:
        printf("Unlock command received\n");
        trig_now = true;
        break;
      case EVENT_NONE:
      default:
        break;
    }

    // measure input voltage, get current pwm output (12V out)
    if (adc_poll(now, &adcVin)) {
      voltage = adc2u(adcVin);
      pwm = v2pwm(voltage);
#ifdef USE_PWM_OUT
      pwm_set_gpio_level(TRIGGER_PIN, trig ? pwm : 0);
#endif
    }
    /*// print it (debug)
    if ((now - tAdcNot) > 2000) {
      tAdcNot = now;
      printf("%0.01fV %d/%d DC\n", (float)voltage/1000.0, PWM_PERIOD, pwm);
    }*/

    // trigger
    if (trig && ((now - tTrig) >= 500)) {
      trig = false;
#ifndef USE_PWM_OUT
      gpio_put(TRIGGER_PIN, trig);
#endif
      r = 0;
      put_pixel(urgb_u32(r,g,b));
    }
    if (!trig && trig_now) {
      tTrig = now;
      trig = true;
#ifndef USE_PWM_OUT
      gpio_put(TRIGGER_PIN, trig);
#endif
      r = 0x80;
      put_pixel(urgb_u32(r,g,b));
    }

    gpio_put(LED_GREEN_PIN, comm_tx_busy());
  }
}

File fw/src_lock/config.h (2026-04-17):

#ifndef __CONFIG_H__
#define __CONFIG_H__

// Name will be used as comm identifier
#define DEV_NAME "KWAK"
#define LOCK_TIMEOUT 1000 // ms
#define STATUS_REPEAT_PERIOD 30 * 60 * 1000

//#define LIFE_LED

// GPIO
#define LED_GREEN_PIN 13
#define BUTTON_PIN 12
#define TRIGGER_PIN 14
#define LOCK_PIN 15
#define SENSE_ADC_PIN 26

// Voltage sense ADC
#define SENSE_VIN_PIN 26
#define SENSE_VIN_ADC 0

#define ADC_POLL_PERIOD 2
#define ADC_OVERSAMPLE 4

#define PWM_PERIOD 62500 // 5kHz
#define VOLT_FULL_PWR 13000 // mV

//#define TIME_POLLING_PERIOD 1000 // ms

#endif // __CONFIG_H__

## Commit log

2025-09-26 lock trigger schematic
    [trigger.kicad_pcb, trigger.kicad_sch]
2025-09-26 led to blink, otherwise it'll never work
    [trigger.kicad_sch]
2025-09-28 pico examples submodule
2025-09-28 non specified schematic changes (led, maybe?)
    [trigger.kicad_sch]
2025-10-02 I2C port scanning
2025-10-02 display and rtc module
    [trigger.kicad_sch]
2025-10-07 button .. will be, one day, maybe
2025-10-07 test button states
2025-10-07 improved model
    [zamek_kachnik.FCStd]
2025-10-16 opening spring holder
    [pruzina_kachnik-drzak_pruziny.3mf, pruzina_kachnik-prichytka.3mf, pruzina_kachnik.FCStd]
2025-10-16 saving mech project
    [pruzina_kachnik.FCStd, zamek_kachnik.FCStd]
2025-10-16 schematic - uart connection (radio)
    [trigger.kicad_sch]
2025-10-17 new models
    [pruzina_kachnik-prichytka.3mf, pruzina_kachnik.FCStd, zamek_kachnik-drzak_zapadky.3mf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]
2025-10-17 trying to make uart tx on interrupt
2025-10-18 uart comm with buffers
2025-10-18 spacer, because of space
    [zamek_kachnik-podlozka.3mf, zamek_kachnik.FCStd]
2025-10-27 move time event resolver to events
    [config.h, events.c, main.c]
2025-10-30 some new packages
    [trigger.kicad_pcb, trigger.kicad_sch]
2025-10-31 yet another oled footprint
    [trigger.kicad_pcb, trigger.kicad_sch]
2025-12-18 motor driver firmware
2026-03-07 KwakKey functional prototype
2026-03-15 pcb design
    [trigger.kicad_pcb, trigger.kicad_sch]
2026-03-21 motor status unknown
2026-03-21 pwm limit in case of overvoltage
2026-03-28 measure voltage, get pwm (not used yet)
2026-03-28 pwm output to save lock coil
2026-03-29 wifi status led blinking (not tested)
2026-04-11 lock connector cover
    [zamek_kachnik_krytka_konektoru.3mf, zamek_kachnik_krytka_konektoru.FCStd]
2026-04-14 push start, timeout, current stop
2026-04-17 bom and some finetuning while first assembly
    [trigger.kicad_pcb, trigger.kicad_sch]
2026-04-17 some nessesary changes on first assembly
2026-04-17 motor driver schematic .. not even started
    [motor.kicad_pcb, motor.kicad_sch]
2026-04-17 some models
    [dins_clip.STL, driver_holder-din_clip2.3mf, driver_holder-thebody.3mf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]
2026-04-20 building motor pcb
    [motor.kicad_pcb, motor.kicad_sch]
2026-05-13 motor driver layout nearly done
    [motor.kicad_pcb, motor.kicad_sch]
2026-05-15 pravdepodobne starsi verze
    [motor.kicad_pcb, motor.kicad_sch]
2026-05-15 layout done, silk screen needed
    [motor.kicad_pcb, motor.kicad_sch]
2026-05-15 silkscreen (partof)
    [motor.kicad_pcb]
2026-05-15 silkscreen almost done
    [motor.kicad_pcb]
2026-05-15 chicken picture missing, only
    [motor.kicad_pcb]
2026-05-15 now its perfect (silkscreen)
    [motor.kicad_pcb]
2026-05-16 chicken squasher hw v1.0 - final touch, fabrication
    [motor-B_Cu.gbr, motor-B_Mask.gbr, motor-Edge_Cuts.gbr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]
2026-08-15 motor driver ibom
2026-08-19 motor driver distance
    [driver_holder-distance.3mf, driver_holder.FCStd]
2026-08-19 bigger kwakhaus lock
    [zamek_kachnik_vetsi-cudlik.3mf, zamek_kachnik_vetsi-cudlik.stl, zamek_kachnik_vetsi-drzak_zamku.3mf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]
2026-09-23 motor current offset (for shitty drivers)
2026-09-23 some 3d prints
    [svetlo-holder.3mf, svetlo.FCStd, zdroj-plate.3mf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]
2026-09-23 measure motor current
2026-10-08 move adc functions out of main
2026-11-02 motor: perceptual (cubic) light dimming curve
    Light PWM was ramped linearly, which looks slow at the start of the fade
    and fast at the end. Keep a linear level ramp (same timings) and map it
    to PWM via a cubic curve so the fade looks even.
2026-11-02 usb wifi adaptor holder and case
2026-11-02 motor: keep light on when LON is sent together with OPEN/CLOSE
    If one message contains both LON and a motor command, the parser pushes
    EVENT_CMD_LIGHT_HOLD, which prevents the auto-off timer from starting
    when the motor stops. Any later motor command, LOFF or the light button
    cancels the hold. Also stop parsing at the message terminator instead of
    scanning stale buffer content.
2026-11-03 door: run on FreeRTOS with io and main logic tasks
    - add FreeRTOS-Kernel V11.3.3 as submodule (fw/ext/FreeRTOS-Kernel)
    - io task (1 ms): ADC, motor driver and current monitoring, light
    dimming/PWM and RGB status LED
    - main task: communication, buttons, events, status reporting and
    light on/off logic; motor controlled through a command queue
    - event queue guarded by critical sections (shared by both tasks)
2026-11-03 door: probe real gate position after reset
    After MOTOR_PROBE_DELAY try to open for up to MOTOR_PROBE_TIME:
    current means the gate was closed, so close it back. No current ->
    try to close: current means it was open, so open it back. No current
    in either direction -> gate status ERROR (reported as "ERROR", status
    LED blinks yellow). Any motor command cancels the probe.
2026-11-03 door: store name and broadcast period in flash, set over USB
    Config (name, broadcast period) lives in the last flash sector and is
    retained over firmware update. USB commands: CFG?, NAME=<name>,
    BRPER=<seconds>. Save is deferred until the motor is idle.
    Fix crc32 (inner loop never ran), use one-page write buffer instead of
    a full sector on the task stack, add magic/version check and fix the
    name_plus overflow in comm_parse.
2026-11-03 door: fix config never saved to flash
    motor_get_pwm() is the voltage-derived duty, never 0 with power on, so
    the deferred save waited forever. Use MOTOR_RUNNING status instead and
    report skipped save when config equals the stored one.
2026-11-03 door: probe needs lasting current to detect movement
    A single noisy ADC sample right after offset calibration counted as
    current, so an open gate was taken as closed and closed back. Current
    must now last MOTOR_PROBE_CURRENT_MIN (100 ms). Log measured currents
    with the probe result.
